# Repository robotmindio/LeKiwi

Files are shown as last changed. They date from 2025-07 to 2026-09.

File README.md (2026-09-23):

# LeKiwi
<div style="display: flex; justify-content: center; align-items: center; padding: 25px;">
    
    
    
    
</div>

> LeKiwi - Low-Cost Mobile Manipulator | Version 1

  

## Step by step tutorial
1. [Bill of Materials](BOM.md)
2. [3D Printing](3DPrinting.md)
3. [Assembly](Assembly.md)
4. [Get started with LeRobot](https://huggingface.co/docs/lerobot/lekiwi)

## Hardware Design
#### Standardized Stacked Base Plates
- Inspired by the [open robotic platform](https://openroboticplatform.com/designrules), our base plates have 3.5mm diameter holes spaced 20mm apart for standardized mounting

#### Power
- (12V version) 12v 5A Li-ion battery
- (5V version) 65W Laptop power bank

> [!TIP]  
> If this is the first time you build robots please choose the 5V version as it’s a little bit easier to assemble. If you are more experienced and want to lift heavier objects choose the 12V version. If you want the cheapest option possible go for the wired LeKiwi version.

#### Compute
- Raspberry Pi 5
- Streaming to a Laptop

#### Drive
- 3-wheel Kiwi (holonomic) drive with omni wheels

#### Robot Arm
- [SO-ARM101](https://github.com/TheRobotStudio/SO-ARM100) ([pinned local CAD source](cad/upstream/SO-ARM100/))

#### Sensors
- Workspace rgb camera
- Wrist rgb camera

## Software Capabilities
Goals:
- Teleoperation with controller or laptop WASD + leader arm
- Data collection pipeline
- Streaming joint angles and camera feed

## CAD Design
[Fusion 360 CAD](https://a360.co/4k1P8yO)

We also provide the [URDF](./URDF/) exported from CAD for simulation.

The open CAD migration is in [cad/](cad/): `LeKiwi_reference.FCStd` preserves the complete STEP reference assembly, while `LeKiwi.FCStd` supplies the editable chassis and accessories. The full Xacro combines that export with the pinned official SO-101 follower model; it keeps LeRobot's stable joint names and the SO-101 kinematics and travel limits. The arm and RobotSkin LD06 sources are pinned in [cad/upstream/](cad/upstream/); initialize them with `git submodule update --init --recursive`. See the [deterministic rebuild instructions](cad/README.md).

The [manufacturing source index](manufacturing/) is the authoritative answer to
what can be edited, cut, or only printed as an STL. It covers every released
print, both laser-cut plates, and the currently identified sourced hardware.

## Check out our Dynamixel Version!
<div style="display: flex; justify-content: center; align-items: center; padding: 25px;">
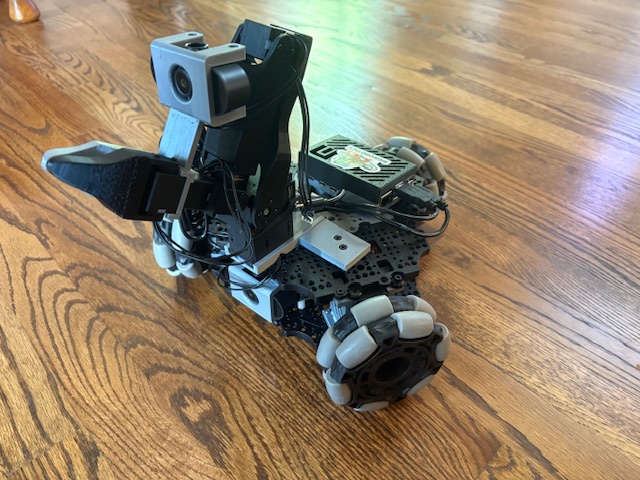
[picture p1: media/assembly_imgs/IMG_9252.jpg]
     
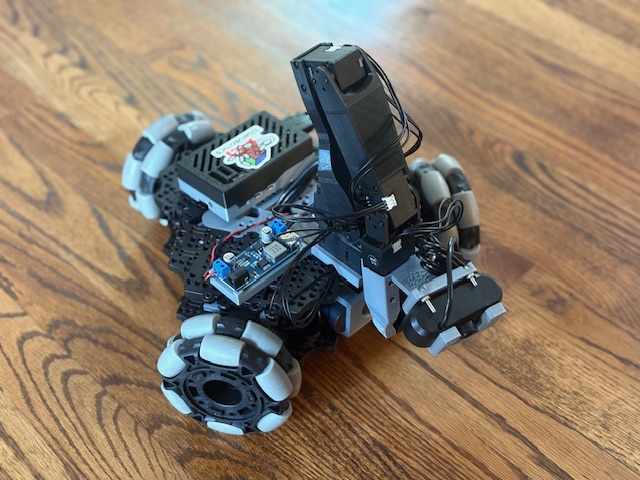
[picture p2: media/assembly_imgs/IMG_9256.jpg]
     
</div>

We converted LeKiwi to use ROBOTIS components by using the Koch v1.1 arm, U2D2 motor controller, and Dynamixel XL430 motors for the mobile base.  [Dynamixel LeKiwi](DynamixelLeKiwi)

## Get In Touch!

Join the project on LeRobot's [Discord server](https://discord.gg/Jtz5TJtb2u) (channel `mobile-so100-arm`)! Let us know if you have any questions, suggestions, or other feedback.

## Citation

If you use LeKiwi in your research, please cite the repository using the metadata in [CITATION.cff](CITATION.cff). GitHub's **Cite this repository** menu provides APA and BibTeX citations.

## Main Contributors
Thank you to everyone who helped on the project!

**CAD Design**: Manav Chandaka, Bhargav Chandaka, Pepijn Kooijmans

**Software**: Pepijn Kooijmans, Gloria Wang, Bhargav Chandaka, Advait Patel

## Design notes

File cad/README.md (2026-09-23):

# Open CAD migration

`assembly/LeKiwi_reference.FCStd` is the complete Fusion STEP export imported into FreeCAD. It is the dimensional reference; STEP cannot retain Fusion sketches or its feature timeline.

`assembly/LeKiwi.FCStd` is the open CAD-to-ROS source for the chassis and accessories. Its active `CadParts` retain the 47-link reference assembly:

- 2 editable FreeCAD laser-cut extrusions;
- 10 links driven by 6 native parametric FreeCAD printed-part sources;
- 23 STEP BREP references; and
- 10 canonical URDF mesh references where the STEP and URDF exports differ by more than 2%; and
- the RobotSkin LD06 base plus lidar body and compact Astra Pro mount.

The final 36-link Xacro replaces that reference assembly's legacy arm subtree with the pinned SO-101 model described below and omits the removed Pi case. The exact source and validation result for every retained CAD link is recorded in [reference_mapping.json](reference_mapping.json). The RobotSkin LD06 body is authored directly in `LeKiwi.FCStd`; its mount and the compact Astra mount are regenerated from their OpenSCAD sources before every export. The hidden `LeKiwiReferenceParts` group is retained only for placement and validation; it is not the geometry exported for a reauthored part.

## Development prerequisites

- **FreeCAD** (tested against the version pinned by the [Flathub `org.freecad.FreeCAD`](https://flathub.org/apps/org.freecad.FreeCAD) package): `scripts/run_freecad_script.sh` launches it as `flatpak run --command=FreeCADCmd org.freecad.FreeCAD`. See `scripts/install_freecad.sh`.
- **OpenSCAD**, on `PATH`, for the RobotSkin lidar/Astra mounts, RobotSkin surfaces, and the reverse-engineered print sources.
- **xacro** and **check_urdf** (ROS Jazzy: `source /opt/ros/jazzy/setup.bash`) to expand and validate the generated Xacro, as `verify_xacro.py` does.
- **Python packages** in [requirements.txt](../requirements.txt) (`pip install -r requirements.txt`) for the scripts that run under plain `python3` rather than FreeCAD's interpreter: trimesh, numpy, shapely, pytest, and vtk for the RobotSkin renderers.
- **CadQuery**: `export_robot.sh` requires it for the native SO-101 wrist. `cad/cadquery/requirements.txt` pins the version CI installs into its own environment; if CadQuery is not installed in the default `python3`, set `CADQUERY_PYTHON` to the interpreter of an environment that has it, e.g. `CADQUERY_PYTHON=/path/to/venv/bin/python3 ./scripts/export_robot.sh`.

## Arm source

The upstream [SO-ARM100](upstream/SO-ARM100/) repository is a pinned Git submodule at
commit `7629d2ad9853d10fb903093a33ef6114099d97e5` under its Apache-2.0 license. The
final URDF and Xacro use its official `Simulation/SO101/so101_new_calib.urdf`
follower model and meshes. `scripts/replace_arm_with_so101.py` performs the one
deterministic integration step: it prefixes the arm links to avoid the ROS
`base_link`, preserves the official inertias, axes, origins, and limits, and maps
the six joints onto LeRobot's stable `arm_*` names.

`cadquery/so101_wrist.py` loads the official STEP geometry for the follower wrist
motor holder and roll carrier. Part 8, the wrist-flex body, is rebuilt from native
CadQuery sketches and features in `cadquery/so101_part8.py`; the STEP remains only
the dimensional reference. Run `python cad/cadquery/test_so101_wrist.py` with
CadQuery installed to check the native solid and the unchanged reference parts.

The export uses that native part 8 as `meshes/so101/native_wrist_flex.stl`, in
the official wrist mesh frame and converted from millimetres to metres.
All other arm meshes are refreshed from the pinned upstream source on every
export. `export_robot.sh` requires CadQuery; set `CADQUERY_PYTHON` to the Python
executable of an existing CadQuery environment if it is not installed in the
default interpreter. `verify_robot.sh` runs its STEP-fidelity check first.
`cad/cadquery/requirements.txt` pins the CadQuery version CI uses.
The export also writes `URDF/LeKiwi.urdf`, the plain-URDF expansion of the Xacro
for consumers without xacro; `URDF/LeKiwi.baseline.urdf` is the original
upstream model that the migration and semantics checks compare against.
`verify_robot.sh` rebuilds everything in a scratch directory and fails if the
committed Xacro, URDF or meshes differ from that rebuild; CI runs it on every
push. The complete export also records `URDF/model-manifest.json`. Run
`python3 scripts/model_manifest.py --check` to detect source or output changes
since the last export; the ROS vendor script runs this check before copying.

The SO-101 base placement is derived from the original assembly's shoulder-pan
datum, not copied from the legacy base-part origin. The importer composes the
CAD joint chain and preserves the shoulder centre and bending plane, then
turns the installed SO-101 outward toward CAD +Y (ROS +X), the arm/fixed-camera
side confirmed by the operator. This half-turn is not a calibration offset.
The pan-frame orientations themselves differ between SO-100 and SO-101;
copying their orientations turns the arm's bending plane by a quarter turn.
Moving that datum in the assembly therefore moves the exported arm correctly.
Both sensor brackets attach to the upper plate's top surface at local z=7 mm.
The lidar reuses the removed Pi case's screw pair at x=+/-20, y=-100 mm,
plus the corresponding y=-80 mm row. Its bracket faces rearward; the lidar
centre is x=-5, y=-135 mm. `verify_sensor_mounts.py` checks all four fasteners
against the actual upper-plate contours. The historical Pi case mounting
datum is retained in `URDF/LeKiwi.baseline.urdf`, not as installed case geometry.
The Astra uses the diagonal pair nearest the operator's two fingernails:
CAD (-100, -20) and (-80, -60) mm, separated by sqrt(2000) = 44.721 mm.
Its bracket centre is (-90, -40, 7) mm and its local yaw is 116.565 degrees,
26.565 degrees counterclockwise from the previous left-facing placement.
The camera faces outward left/rear, retaining the 8-degree downward pitch.

Initialize it after cloning, then check the expected source bundle:

```sh
git submodule update --init --recursive
./scripts/verify_arm_sources.sh
```

The LeKiwi-specific `modified_base_arm` and legacy webcam gripper insert remain
separate prints; they are not part of the SO-101 robot description.

## Link identifiers

Names such as `ST3215_Servo_Motor-v1-1` and
`4-Omni-Directional-Wheel_Single_Body-v1-2` are unique Fusion-assembly
occurrence identifiers, not a sequence of part revisions. Each needs its own
URDF link and pose even when the physical component is the same. Do not delete
or merge them merely because their filenames share a `-1` or `-2` suffix.

## RobotSkin source

`upstream/RobotSkin/` is pinned at commit `b028a962e99f8a84eaebfe314e63373a82edc8c1`.
Its `scad/parts/lekiwi-lidar-base.scad` entry point and shared
`scad/lib/robotskin.scad` implementation generate the lidar mount. The generated
mesh lives under ignored `cad/generated/`; `export_robot.sh` rebuilds it and updates
the assembly before writing the URDF meshes and Xacro.

## Native printed-part sources

The complete LeKiwi-specific manufactured set represented by the URDF is editable in [parts/](parts/README.md): the two laser-cut plates plus `drive_motor_mount.FCStd`, `omni_wheel_mount.FCStd`, `servo_controller_mount.FCStd`, `lipo_battery_mount.FCStd`, `base_camera_mount.FCStd`, and `wrist_camera_mount.FCStd`.

Each printed-part file has an `Editable dimensions` (`Parameters`) object and a normal FreeCAD feature tree ending in `Final`; it contains profile features, Part extrusions, primitives, fuses, and cuts—not an imported mesh or opaque BREP wrapper. Open a source file in FreeCAD, change a parameter or profile feature, and save it. Then relink and regenerate:

```sh
make link-native-part-sources
./scripts/export_robot.sh
make verify-native-part-sources
```

`build_native_part_sources.sh` reconstructs the six initial source files from the validated STEP/STL references. It intentionally overwrites those source files, so use it to reset or regenerate a baseline, not after manual edits you intend to keep.

Four models preserve their STEP component frame. The omni-wheel source uses the canonical URDF mesh frame; the drive-motor source uses the user-selected `3DPrintMeshes/drive_motor_mount_v2.stl` frame. Both use editable native features derived from STL sections. The linker's validation must remain below the 2% geometry tolerance before it saves the assembly.

The v2 motor cages measure 47.5 × 34.8 × 45.5 mm installed. Their three placements
are aligned to the existing chassis bolt holes, 1.25 mm inset from the flats.
`scripts/install_wheel_mount_v2.py --apply` updates the six cage/servo joint poses,
the visible complete wheel units and `wheel_mount_v2_poses.json`; without `--apply`
it checks the installation. Six rods occupy (±100, 0) and (±60, ±80) mm.
RobotSkin uses 4 mm per-side wheel-unit clearance from this corrected geometry.

Published, non-URDF accessory sources live in [accessories/](accessories/README.md). At present, the two webcam mounts have exact LeKiwi STEP sources and are imported as editable BREP documents; their source files are not duplicated or hand-recreated.

## Deterministic build

After changing a source or robot metadata, run:

```sh
./scripts/verify_robot.sh
```

The verifier generates the assembly, meshes, and Xacro under a temporary build
directory and removes it when finished, so checking the model does not rewrite
the source tree. Run `export_robot.sh` when the validated generated files should
be promoted into `URDF/`. It exports the FreeCAD link sources to
`URDF/meshes/reauthored/`, replaces the legacy arm subtree with the pinned
SO-101 follower, and writes the complete Xacro. There is no hand-edited Xacro
step. `verify_cad_migration.sh` checks every retained CAD link against the
baseline URDF; the SO-101 links remain verified directly against their pinned
upstream source.

The slower reconstruction of legacy and recovery manufacturing files is a
separate audit because those files do not feed the robot Xacro:

```sh
./scripts/verify_manufacturing.sh
```

`native_parts.json` is the source of truth for the six parametric printed-part documents, their assembly links, and their placement references.

For a stricter shape-fidelity audit, run:

```sh
make compare-reauthored-assets
```

It compares each native FreeCAD export with its configured reference mesh using
bidirectional sampled surface distance and fails on more than 0.25 mm maximum
or 0.10 mm 95th-percentile deviation. Pass `ARGS=--report-only` to only write
the comparison report without failing the run. The checked-in baseline
uses the v2 STL for all three motor cages (0.211 mm maximum, 0.041 mm p95
sampled deviation); this remains separate from the older bounding-box and volume check.
`verify_robot.sh` runs this check in its strict (default) mode.

## Mass and inertia

Native source links deliberately keep `UseCadMass=False` until a real material density or printed mass is known. After choosing material or measuring a finished part, activate CAD-derived mass, centre of mass, and the full inertia tensor for the relevant assembly link:

```sh
make attach-cad-part ARGS="cad/assembly/LeKiwi.FCStd drive_motor_mount-v11-2 CadDriveMotorMountV11_2 1240 0"
./scripts/export_robot.sh
```

Here `1240` is only an example density in kg/m³. Use a measured printed mass instead of `0` for FDM or assembled parts; it accounts for infill, walls, and hardware. The exporter combines all solid CAD parts in a link with the parallel-axis theorem. Purchased components should use measured or vendor mass overrides. `verify_xacro.py` does not exact-match a `UseCadMass=True` link's `<inertial>` against the baseline URDF (which never had real CAD mass); instead it checks the exported mass and inertia tensor physically: positive finite mass, a positive-definite inertia tensor, and principal moments that satisfy the rotational triangle inequality.

Chassis joint metadata remains editable in the `LeKiwiJoints` group. SO-101 joint names, parents, children, axes, origins, and limits come from the pinned upstream URDF; together they form the deterministic composite Xacro contract.

### Measured chassis rod placements

The six screws identified by the operator in the marked underside photograph
are existing 20 mm-grid holes at `(±100, 0)` and `(±60, ±80)` mm. The working
`assembly/LeKiwi.FCStd` places all six existing rods there, with no central rod.
The visible rod placements and their ROS joint poses are both corrected. The
upper plate remains at `(0, 0, 50)` mm; its joint offset compensates for moving
the rod that is its parent. The original `LeKiwi_reference.FCStd` stays unchanged.

Run `./scripts/run_freecad_script.sh scripts/correct_chassis_rods.py` to verify
all six placements against holes in both editable plates. Add `--apply` to
reapply this measured layout. This does not resize the motor stands. Regenerate
RobotSkin exports after chassis corrections; old generated skins are not current.

## Rebuild after replacing the Fusion STEP export

```sh
make import-step-reference
make seed-robot-metadata
make build-laser-plate-sources
make verify-laser-plate-sources
make build-native-part-sources
./scripts/migrate_reference_links.sh --apply
make link-base-plate-sources
make link-native-part-sources
./scripts/migrate_reference_links.sh --apply
./scripts/run_freecad_script.sh scripts/correct_chassis_rods.py --apply
./scripts/run_freecad_script.sh scripts/install_wheel_mount_v2.py --apply
./scripts/export_robot.sh
make verify-native-part-sources
```

`correct_chassis_rods.py --apply` and `install_wheel_mount_v2.py --apply` must
run after the assembly's base plates and native parts are linked (so their
holes and reference geometry exist to validate against) and before the final
`export_robot.sh`, so the corrected chassis-rod and v2 wheel-mount placements
are baked into `cad/assembly/LeKiwi.FCStd` before the Xacro and meshes are
generated from it.

The first migration pass creates hidden placement references. The second records the validated native sources after they have been linked.

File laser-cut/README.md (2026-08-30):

# Laser-cut base plates

`generated/` contains the editable, millimetre DXF profiles for the lower and
upper base plates used by the validated Fusion/URDF assembly. They are the
canonical cut geometry; [`base_plates.scad`](base_plates.scad) selects one for
convenient OpenSCAD export, and `build_laser_plate_sources.py` turns each into
its FreeCAD extrusion source.

`generated/print-templates/` contains matching 1:1 PDF templates for paper printing. Print at **Actual size / 100%** (never “Fit to page”); each PDF page is 216 × 213 mm. If the printer crops them, use the `*_tiled_a4.pdf` version: print both A4 pages at 100%, cut on the dashed `CORTAR/UNIR` line, and tape the two halves together.

Export a selected profile to another DXF with OpenSCAD:

```sh
openscad -D 'plate="lower"' -o /tmp/base_plate_lower.dxf base_plates.scad
openscad -D 'plate="upper"' -o /tmp/base_plate_upper.dxf base_plates.scad
```

They match the current assembly plates, including through-holes and upper-plate
cutouts. The older `3DPrintMeshes/base_plate_layer2.stl` has a different
outline; its separate editable legacy profile is tracked with the standard
reverse-engineered print sources. Set material thickness and kerf compensation
in the laser-cutter software; neither changes the 2D profile.

The native Fusion archive, whole-assembly STEP, and whole-assembly DXF are retained in `../reference/fusion/`. The Fusion archive is the only export that preserves the original feature history.

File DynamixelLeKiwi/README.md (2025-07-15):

# Our Dynamixel Version!

 

 

1. Buy the parts following the [BOM](BOM.md)
2. Print all the parts listed in [3DPrinting](3DPrinting.md)
3. Follow our [Assembly](Assembly.md) to build the dynamixel LeKiwi

## Modified Lerobot Code For Teleoperation 

Here are the changes we made to the original LeKiwi code: [Dynamixel Teleop](https://github.com/SIGRobotics-UIUC/lerobot/commit/cc4adff50d33ef14ab579abfe554689732d0e5e5)

You can follow the original LeKiwi documentation with this modified code. Make sure to change ports, ips, etc. for your specific setup.

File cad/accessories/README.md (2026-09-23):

# Published accessory sources

The [RobotSkin chassis overlays](ROBOTSKIN_SURFACES.md) cover the exterior top,
interior floor and interior ceiling. Their OpenSCAD recipe derives clearances
from the installed chassis and builds a separate FreeCAD review assembly.

This directory contains FreeCAD documents only when an exact, redistributable
editable source is already published with LeKiwi. They are intentionally kept
outside the URDF assembly: webcam mounts are alternative camera hardware, not
the Arducam configuration represented in `LeKiwi.FCStd`.

| Accessory | Published source | FreeCAD document | Source kind |
| --- | --- | --- | --- |
| Webcam base mount | `3DPrintMeshes/webcam_mount/webcam_mount.step` | `webcam_base_mount.FCStd` | Imported STEP BREP |
| Webcam wrist mount | `3DPrintMeshes/webcam_mount/webcam_mount_wrist.step` | `webcam_wrist_mount.FCStd` | Imported STEP BREP |
| SO-100 webcam gripper insert | `cad/upstream/SO-ARM100/STEP/SO100/Follower_Specific/Wrist_Roll_08c v1.step` + editable M3 clearance and hex-nut pocket | `so100_gripper_cam_mount_insert.FCStd` | SO-ARM100 STEP derivative |

## Compact base-removed Astra Pro mount

[`astra_pro_compact_mount.scad`](astra_pro_compact_mount.scad) is a direct,
low-profile adapter for the clear space between two wheels. It keeps the camera
upright at 8 degrees downward pitch. The base has two blind M3 insert sockets at
44 mm centres;
the camera saddle has two M2 holes at 18.0 mm centres and a
26.2 x 7.4 x 6.3 mm pocket. Its plan dimensions use the measured 0.6 and
1.3 mm play in the previous 26.6 x 8.5 mm print, leaving 0.2 mm total clearance
on each axis. The M2 holes remain centered in the pocket on the lens-to-USB
axis. Their head-access bores are 4.7 mm for the measured 4.5 mm screw heads.

The camera contact plane is only 15.5 mm above the LeKiwi plate. Heat-set two
M3x4x4 inserts from below into the large plate-facing surface, attach the camera
using its M2x8 screws, then drive the M3 screws upward through the LeKiwi plate.
The 4.0 mm diameter sockets are 4.2 mm deep; tune `m3_insert_hole` if the actual
insert or printer needs a different fit. Print flat on its base:

```sh
openscad --export-format binstl -o 3DPrintMeshes/astra_pro_compact_mount.stl cad/accessories/astra_pro_compact_mount.scad
```

Build or reset those documents, then verify that they still match their
corresponding print STLs:

```sh
make build-accessory-sources
make verify-accessory-sources
```

These are editable Open STEP BREP documents in FreeCAD's Part workbench. The
SO-100 derivative keeps its upstream wrist-roll BREP and its M3 camera-mount
boss as a separate editable cylinder/fuse. The upstream wrist-roll revision is
within 0.191% by volume but differs by 2.325% in bounding box from LeKiwi's
legacy print, so this derivative is not presented as an exact reconstruction.
None are claimed to reconstruct the original parametric feature history.

## External or non-identical sources

| Accessory family | Source found | Why it remains external |
| --- | --- | --- |
| Raspberry Pi case top and bottom | [Printables model 605060](https://www.printables.com/model/605060-raspberry-pi-5-case-wpower-button-v2) publishes STEP files | Its CC BY-NC terms cannot be silently relicensed under this repository's Apache-2.0 license. The LeKiwi STLs are described as modified from that model, so the public STEP is not assumed to be an exact replacement either. |
| Standard SO-100/SO-101 arm | [TheRobotStudio/SO-ARM100](../upstream/SO-ARM100/) publishes Apache-2.0 STEP sources | The repository is pinned as a Git submodule. The SO-100 follower source is checked by `scripts/verify_arm_sources.sh`; `modified_base_arm` is not verified as an exact upstream part. |
| VEX-derived wheel hub | VEX provides downloadable CAD for its parts | `servo_wheel_hub.stl` is documented as modified from a VersaHub, not as an unmodified vendor part. No exact Apache-compatible source for the LeKiwi derivative was established, so the vendor file is not vendored here. |

## Reauthoring candidates with no exact editable source located

The search covered the LeKiwi repository history, its Fusion archive, and the
published upstream projects above. The following print assets still need a
native reauthoring if they are to become editable FreeCAD sources:

- `3DPrintMeshes/battery_mount_eu.stl` and `5v_specific/5v_power_bank_holder.stl`
- `3DPrintMeshes/drive_motor_mount_v2.stl`
- `3DPrintMeshes/modified_base_arm.stl`, `jetson_holder.stl`, and `wrist_camera_mount.stl`
- `3DPrintMeshes/wired_specific/cable_holder v0.stl` and `wired_specific/usb_connector_case v1.stl`
- `3DPrintMeshes/dynamixel_specific/Dynamixel_omni_wheel_mount v2.stl`, `center_triangular_insert.stl`, `dynamixel_drive_motor_mount.stl`, `dynamixel_kiwi_servo_mount.stl`, `dynamixel_modified_base_arm.stl`, `dynamixel_wheel_hub .stl`, `follower_base.stl`, `modified_static_side_with_mount.stl`, `pi_case_bottom.stl`, and `webcam_base_mount.stl`

`drive_motor_mount.stl`, `servo_wheel_hub.stl`, `servo_controller_mount.stl`,
`battery_mount.stl`, `base_camera_mount.stl`, and
`dynamixel_specific/lipo_battery_mount.stl` correspond to existing native
URDF sources, so they are not missing-source candidates.

The `drive_motor_mount_v2.stl` and `wrist_camera_mount.stl` print revisions do
not match their older URDF counterparts, so the current native URDF sources
must not be presented as editable sources for those two files.

The core URDF source files in `cad/parts/` are tracked separately. Their
current geometric-fidelity audit is recorded in
`cad/validation/reauthored_asset_comparison.json`; all twelve native link
instances pass its sampled surface criterion. That validation does not extend
to the alternative accessory prints listed above.

## Core native-source fidelity

The two laser plates and all six native printed sources pass the strict
bidirectional sampled surface audit against their corresponding original URDF
meshes. The maximum measured deviation is 0.056 mm and the largest 95th
percentile is 0.034 mm.

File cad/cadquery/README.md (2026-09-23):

# Part 8 physical simplification

`so101_part8_simplified.py` replaces a curved section of the lower skirts with
a planar facet between the motor rails and the lower seat. The cut starts
beyond the rails at x=-10.5 mm and stops before the seat at x=9.8 mm. Keeping
the rail support intact limits how much of this contour can be straightened.

This version modifies the exact pinned upstream STEP. It is **STEP-backed**,
not a new native reconstruction. `so101_part8.py` remains the separate native
approximation used by the robot exporter; this candidate does not replace it.

The original source is loaded once with `so101_wrist.load_part("flex_body")`
and passed to `part8_simplified(original)`. Both the source geometry and the
comparison therefore use one source of truth. The recipe contains only the
facet coordinates and extrusion; mounting geometry is not duplicated.
`cad_checks.py` shares solid comparison and STL validation/export, and
`render_stl_comparison.py` can compare other arm meshes at matching scales.

## Reproduce

From the repository root, using an interpreter with CadQuery and its VTK
dependency installed:

```sh
python cad/cadquery/test_so101_part8_simplified.py
python cad/cadquery/render_stl_comparison.py \
  cad/generated/part8/so101_part8_original.stl \
  cad/generated/part8/so101_part8_simplified.stl \
  cad/generated/part8/comparison.png
```

The check exports both STL files in millimetres and the same coordinate frame,
plus `comparison.json` with source hash, geometric measurements and mesh checks.

## What is checked

- Both solids and both boolean differences must be valid. Equal-volume boxes
  at different positions serve as a negative control for shape equality.
- No added material, so the candidate cannot introduce a new geometric
  collision at any joint angle. This preserves existing clearance; it does
  not certify that the original assembly itself is collision-free.
- The original cylindrical mounting faces retain their topology. Protected
  regions around the motor rails/heel, roof/ears, seat/foot and clip lose no
  material. No joint frame, axis or mounting location is moved.
- Both STL meshes must be closed, manifold and connected, and their volumes
  must agree with CAD within 0.1%. Export uses absolute 0.02 mm deflection.
  VTK removes zero-area facets caused by binary STL rounding; holes are not
  patched and surfaces are not smoothed. CAD volume accounting permits 1 mm³
  integration error on split spline faces, separately from the zero-addition
  shape check.

This is a conservative geometric prototype. Material, layer orientation,
supports, stiffness and fatigue have not been physically qualified. Closed
STL geometry does not establish support-free printing or equal strength.
Further structural simplification needs the intended loads and print setup.

## Single-piece rounded redesign

`so101_part8_serviceable.py` retains its historical filename but now builds
**one piece**: a smooth motor cradle with integral curved sides and a mirrored
fork. The cover builders, seams, windows, screw bosses, inserts, cable-tie
tunnels and cover calibration parameters are gone. The outside is 37 mm wide,
versus 34 mm for the preceding single-piece version, and its nose extends
4 mm farther forward. This extra envelope lets the housing wrap around the
lower seat instead of leaving an external shelf. The motor opening stays open;
this is not a sealed enclosure or a lightweight optimization.

The fork no longer has separate flared collars. Its inner junctions are blended
after union with the housing; the rear outer face meets the back curve without
a bottom-edge fillet interrupting the join. R60 side surfaces and R3 edge blends
replace the shallower R80 sides and R2 rim. A tangent-ended lower profile flows
down to the seat, and the deck's exposed upper edges have R0.6 rounding. Sharp
motor-contact and access edges are not indiscriminately rounded.

The bottom tooth is removed at the user's request. It previously contacted the
rotating wrist outside the configured motion range, consistent with a travel
stop. **That mechanical stop no longer exists.** The software limits have not
been expanded; do not assume the old physical end-stop/calibration behavior.

The incoming wrist-flex axis stays at (-18.1, 0, 28) mm along X and outgoing
wrist-roll at (0, 0, -33.1) mm along Z, within the pinned URDF's rounding.
Motor placement, joint transforms, link lengths and software limits are unchanged.
Mass, stiffness and payload capacity are not guaranteed equivalent.

This remains a hybrid native/STEP-backed design. Native rounded geometry defines
the shell and fork; exact source patches retain the motor contacts, rails,
joint faces and mounting holes. The lower-seat patch ends at Z=-34.4 mm rather
than importing the tooth underneath, and is limited to Y=±12.4 mm so it does not
restore the old outer skirt edges. This retains the motor seats and the mounting
counterbores (which reach Y=±12.25 mm). The deck retains the original planar
contact footprint and access opening. The original source is never modified.

### Generate and inspect

```sh
python cad/cadquery/test_so101_part8_serviceable.py
python cad/cadquery/render_part8_serviceable.py
```

Current outputs are in **`cad/generated/part8-smooth/`**:

- `original.stl` and `cradle.stl`: matching original assembly coordinates, mm.
- `cradle_print.stl`: the same single part oriented with its left ear down.
  Inspect supports for the deck and lower seat in your slicer; this is not a
  support-free or physically qualified print.
- `cradle.step`: editable solid.
- `preview.png`: actual original/redesign/underside views at equal scale.
- `details.png`: close-up fork/deck, front opening, rear and underside views.
- `checks.json`: source hashes, exact-interface and sampled-clearance results.

The older `part8-serviceable/` generated files are superseded. They are not
outputs of this builder; do not print their covers for this version.

### Assembly and checks

Use the original motor/joint hardware. There are no additional cover screws or
heat-set inserts. The open front provides motor access; the fork-root opening
clears the motor's top tab. Removing the motor still requires its fasteners and
possibly the neighboring joint to be removed.

Checks compare added/removed material in the five protected contact regions and
counterbore seating layers—not just total volume. They also check the empty
counterbores, absence of the tooth and old raised deck fragments, uninterrupted
side walls, and absence of the old fork-patch seam. Each STL must be closed,
manifold, connected and within 0.1% of CAD volume.

The actual pinned motor and immediate neighboring meshes are sampled across
259 configurations, with wrist angle spacing no greater than 2°. New
penetration beyond 0.08 mm relative to upstream fails. Front motor entry is
also compared to upstream in both sampling directions at 61 translations over
60 mm. The source model already has clip/guide interference, so this is **not**
proof of a rigid, force-free insertion path.

These are finite geometric checks, not continuous swept-volume proof, whole-arm
collision certification, or bench validation. Physical assembly, cable routing,
print fit, cooling, strength and fatigue still need testing. Start with a fit
prototype and retain the software motion limits.

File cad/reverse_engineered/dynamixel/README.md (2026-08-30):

# Dynamixel print sources

`parts.json` is the source and validation manifest for every Dynamixel-specific
print.  It records the original STL's unit conversion, the canonical editable
source, and the bidirectional surface-comparison result.  Native Fusion files
remain at [the public Fusion share](https://a360.co/44YAcMn): it has no stated
redistribution licence, so this repository stores stable component identifiers
and hashes instead of a copy.

## Local sources

The three legacy prints not currently validated as matching exportable Fusion
bodies are editable locally.  `dynamixel.scad` reconstructs the arm and drive
mount from closed DXF sections; `lipo_battery_mount.scad` is a direct parametric
tray model.  All dimensions are millimetres.  Build ignored STLs locally with:

```sh
cd cad/reverse_engineered/dynamixel
openscad -D 'part="dynamixel_modified_base_arm"' -o generated/dynamixel_modified_base_arm.stl dynamixel.scad
openscad -D 'part="dynamixel_drive_motor_mount"' -o generated/dynamixel_drive_motor_mount.stl dynamixel.scad
openscad -o generated/lipo_battery_mount.stl lipo_battery_mount.scad
```

The arm uses the coarsest tested 16-section stack that passes the 0.25 mm maximum
and 0.10 mm p95 surface gate.  The drive mount uses the coarsest tested passing
uniform stack: 230 sections at 0.239565210757 mm.

## Static-side patch

Open the `Static Side Gripper` source from the public Fusion share, select its
small BRep body, and run `patch_static_legacy_hole.py` from Fusion's Scripts and
Add-Ins dialog.  It adds the one missing legacy R3.149941806669 mm finite
through-hole as a native Combine/Cut feature.  Export the patched body together
with the unchanged large Static Side Gripper body to produce the original
two-body print.

`validation/verify_static_composition.py` is a manual external-source
composition check.  Export both public-source bodies as separate, uncommitted
STLs: the unpatched small body first and the unchanged large body second.  Run
the verifier in FreeCAD's Python console.  It directly performs a
bidirectional *sampled* surface comparison for the large body against its own
target component.  For the small body, it checks sampled source-to-target and
target-to-source distances outside exactly the 52 fitted hole faces, then checks
the fitted faces against the patch radius and finite endpoints.  It reports
`compositional_pass`, deliberately distinct from a direct patched-small-body
export comparison; the public STEP proxy is not used as an export surrogate.

```python
import runpy, sys
sys.argv = [
    "verify_static_composition.py",
    "/absolute/path/to/static_a_small_body.stl",
    "/absolute/path/to/static_b_large_body.stl",
]
_ = runpy.run_path("/absolute/path/to/verify_static_composition.py", run_name="__main__")
```

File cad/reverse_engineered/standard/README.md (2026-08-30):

# Standard LeKiwi print-source recovery

`standard.scad` has one selector per reauthored solid.  For example:

```sh
openscad -D 'part="servo_wheel_hub"' -o generated/servo_wheel_hub.stl standard.scad
```

`legacy_base_plate_layer2.dxf` is an editable 2D cut contour; its SCAD file
extrudes it to the original 7 mm thickness.  The three Fusion entries retain
their original feature-history members in `LeKiwi.f3z`; their exported solids
are surface-validated in `validation/provenance.json`.

The mesh-only solids use editable DXF section stacks.  `parts.json` maps each
part to its selector and `validation/results.json` records its surface check.
The strict gate is the shared `compare_reauthored_assets.py --mesh-align`
check: 1,024 deterministic bidirectional surface samples.
Jetson's original STL has overlapping bodies, so its three watertight bodies
are checked separately and the `jetson_holder` selector is only their preview
union.

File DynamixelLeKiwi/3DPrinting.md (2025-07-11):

# 3D Printing
> **Estimated time:** ~34 hours

We provide ready-to-print STL files for the 3D-printed parts below. These can be printed with generic PLA filament on consumer-grade FDM printers. We tested on a [Bambu Lab P1S](https://us.store.bambulab.com/products/p1s) printer. For all components, we just load into bambuslicer, auto-rotate and auto-arrange, enable any recommended supports, and print.

## Parts

| Item | Quantity | Notes | 
|:---|:---:|:---:|
| [Center triangular insert](/3DPrintMeshes/dynamixel_specific/center_triangular_insert.stl) | 2 |  |
| [Dynamixel Drive motor mount](/3DPrintMeshes/dynamixel_specific/dynamixel_kiwi_servo_mount.stl) | 3 | |
| [Dynamixel Servo wheel hub](/3DPrintMeshes/dynamixel_specific/Dynamixel_omni_wheel_mount%20v2.stl) | 3 | Use Supports<sup>[1](#footnote1)</sup> | |
| [Lipo battery mount](/3DPrintMeshes/dynamixel_specific/lipo_battery_mount.stl) | 1 | |
| [RasPi case Top](/3DPrintMeshes/pi_case_top.stl) | 1 | <sup>[2](#footnote2)</sup> |
| [RasPi case Bottom](/3DPrintMeshes/dynamixel_specific/pi_case_bottom.stl) | 1 | <sup>[2](#footnote2)</sup> ||
| Webcam [base mount](/3DPrintMeshes/dynamixel_specific/webcam_base_mount.stl), [static gripper w/ mount](/3DPrintMeshes/dynamixel_specific/modified_static_side_with_mount.stl) | 1 | **Compatible with [this camera](https://www.amazon.fr/Vinmooog-equipement-Microphone-Enregistrement-conférences/dp/B0BG1YJWFN/)** |
| [Modified Follower Arm Base](/3DPrintMeshes/dynamixel_specific/follower_base.stl) | 1 |  |
| [Follower arm](https://github.com/jess-moss/koch-v1-1) | 1 |Use with the modified base and static gripper  |
| [Leader arm](https://github.com/jess-moss/koch-v1-1) | 1 | |

> **Note**: Make sure to enable supports where specified!

## Printing Instructions
Assuming you already have access to a 3D printer<sup>[3](#footnote3)</sup>, follow these steps to print all the parts above.

### 1. Setup Printer
1. Calibrate the printer and level beds according to printer-specific instructions
2. Clean the print bed
3. Load-in filament

### 2. Print the Parts
1. Upload STL file to printing/slicing software. Auto-rotate and auto-arrange. 
2. Enable supports if specified and slice. We tested with the following settings:
    - Infill Density: 15%
    - Layer Height: 0.2 mm
    - Printing Speed: 150 mm/s
3. If needed, upload G-code (slice file) to printer and print

### 3. Take Down
1. Remove printed part(s) from printer
2. Clean print bed if needed
3. Remove any supports from printed parts

> For tutorials on how to assemble the robot, checkout the [Assembly](Assembly.md) page!

## Footnotes
<a name="footnote1">1</a>: Modified from [VEX VersaHub model](https://www.vexrobotics.com/versahubs.html?srsltid=AfmBOooDKLcAfkuEgHyrjk24WFDrLTP4TQWkGjEpC-9HcyaMMCUMDSzs)

<a name="footnote2">2</a>: Modified from [Micro Center model](https://www.printables.com/model/605060-raspberry-pi-5-case-wpower-button-v2)

<a name="footnote3">3</a>: If not, we recommend [Bambu Lab](https://bambulab.com/en-us) or [Prusa](https://www.prusa3d.com/), or checkout this [list of brands](https://github.com/ad-si/awesome-3d-printing?tab=readme-ov-file#3d-printer-brands).

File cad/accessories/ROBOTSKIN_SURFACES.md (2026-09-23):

# Superficies RobotSkin para LeKiwi

Tres recubrimientos de 4 mm: `top.stl` (Z=57–61), `floor.stl` (Z=0–4) y
`ceiling.stl` (Z=46–50, puertos hacia abajo), en milímetros del chasis.

## Fuente de las posiciones

El soporte autoritativo es `3DPrintMeshes/drive_motor_mount_v2.stl`, indicado
por el usuario. Su reconstrucción paramétrica mide **47.5 × 34.8 × 45.5 mm**
(ancho tangencial × profundidad radial × altura instalada), no 50 × 37 mm.
Los cuatro ejes de fijación de cada soporte coinciden con agujeros del chasis;
el borde exterior queda 1.25 mm dentro del segmento plano. Las tres unidades
se orientan a 120°, con los ejes de rueda radiales y los planos tangenciales.

Soportes, motores, cubos, ruedas y seis separadores se obtienen de los `CadParts`
activos y las posiciones articulares de `cad/assembly/LeKiwi.FCStd`.
Los separadores están en (±100, 0) y (±60, ±80) mm, en los tornillos señalados.
El brazo SO-101 y los accesorios conservan sus transformaciones actuales.

Los recortes reservan **4 mm por cada lado** de las envolventes convexas XY
de las unidades de rueda que alcanzan la altura de cada piel. La huella nominal
del soporte con ese margen mide 55.5 × 42.8 mm; otros componentes pueden
ampliar el recorte. `--motor-clearance` ajusta el margen independientemente
de las otras holguras. `motor_bases` conserva las huellas y recortes verificados.
El techo también deja espacio para los soportes de 45.5 mm de altura.
Los seis separadores se comprueban en las tres pieles.
Las dos ventanas de cables se derivan del perfil CAD superior: 60 × 20 mm
centrada en (0, 0) y 20 × 30 mm en (0, 50), ambas con esquinas R4.
Son aproximaciones de la fotografía usando la retícula de 20 mm, no medidas
con calibre. El techo conserva ambas; la piel superior también las despeja,
aunque pueden unirse al recorte del brazo. El piso no cambia.
La holgura general se ajusta con `--clearance` (0.5–3 mm); el borde exterior queda
0.5 mm dentro del perímetro de la placa. Los componentes electrónicos no
recortan la piel: se remontarán encima, según el montaje solicitado.

## Fijación usando los puertos normales

No hay agujeros adicionales para fijar la piel. Todos los puertos usan `port_cut()`
y el paso central de `through_plate()` de la biblioteca RobotSkin existente.
La retícula de 10 mm parte del origen del chasis, por lo que coincide con su
retícula de tornillos de 20 mm. `chassis_ports` en `checks.json` enumera los
puertos que coinciden con agujeros físicos utilizables de cada placa.

Las cuatro fijaciones del brazo señaladas en la foto tienen claros independientes
de Ø12 mm para cabezas, tuercas y arandelas, derivados de los agujeros mayores
del CAD superior: (-31.727, 25.225), (31.773, 25.225), (-27.753, 95) y
(27.799, 95) mm. `--arm-fastener-diameter` permite ajustar el acceso (8–16 mm)
a la tornillería real. El techo contiene los cuatro agujeros; en la piel superior
quedan dentro del recorte abierto del brazo. No se taladra ni se cambia la placa.
Esta corrección no modifica la colocación del brazo en el ensamblaje.
El STEP `Base_SO101.step` confirma el patrón: pares de 63.5 y 55.55 mm de ancho,
separados 69.775 mm. Los claros siguen los agujeros físicos confirmados, no el
desplazamiento de la instancia del brazo; ese desfase CAD permanece sin corregir.

Fijar las pieles por esos mismos puertos, con tornillos M3 y los insertos de
RobotSkin. Usar un único inserto por unión: no enroscar un tornillo a través
de dos insertos enfrentados. La placa superior con sus dos pieles suma 15 mm;
la inferior con su piel suma 11 mm. Elegir la longitud según cabeza, arandelas
y enganche del inserto. Se conservan los ajustes de impresión `RM_PORT_FIT`,
`RM_PEG_FIT` y `RM_INSERT_BORE` de la biblioteca fijada por LeKiwi.

## Regenerar e inspeccionar

Requiere FreeCAD Flatpak, OpenSCAD y Python con trimesh, Shapely 2 y rtree;
las imágenes usan VTK. Desde la raíz del repositorio:

```sh
./scripts/build_robotskin_surfaces.sh
python3 scripts/render_robotskin_surfaces.py
python3 scripts/render_robotskin_assembly.py
```

Resultados en `cad/generated/robotskin/`:

- `top.stl`, `floor.stl`, `ceiling.stl`: impresión con puertos arriba y base Z=0.
  El techo se refleja en Y para recuperar las coordenadas CAD al voltearlo.
- `LeKiwi_RobotSkin.FCStd`: ensamblaje de revisión con las pieles instaladas.
- `preview.png`: las tres pieles y despiece.
- `full_build.png`, `wheel_assemblies.png`: CAD corregido y unidades de rueda.
- `floor_base_fit.png`: STL del piso y huellas v2 con 4 mm por lado.
- `floor_wheel_fit.png`: piso instalado y conjuntos completos de rueda.
- `upper_windows.png`: ventanas del CAD superior y techo en coordenadas instaladas.
- `arm_fastener_access.png`: cuatro accesos del brazo resaltados en verde.
- `checks.json`, `wheel_orientation_checks.json`: geometría, fijaciones y ejes.

Las verificaciones exigen mallas cerradas y conectadas, grosor de 4 mm, paso
central libre en todos los puertos y caras dentro de las envolventes comprobadas
(tolerancia STL de 0.002 mm). Los componentes que se remontarán se muestran en sus
posiciones de referencia en la vista del robot completo.

La altura interior libre queda en 42 mm. Las piezas caben aproximadamente en
215 × 212 mm. Falta la prueba física de ajuste, incluida la tornillería real
del brazo, y no se certifica el barrido completo de sus seis ejes.

La referencia de servo tiene pequeñas intersecciones de esquina con el soporte
v2 (menos de 1 mm³ por unidad, también presentes contra el STL original).
Esto no es una colisión con RobotSkin ni una certificación de ajuste físico
servo/soporte. No se ha deformado el soporte oficial para ocultarlas.

Verificación del 2026-09-08: `verify_robot.sh`, `compare_reauthored_assets.sh --strict`,
`verify_robotskin_surfaces.py`, `correct_chassis_rods.py` e `install_wheel_mount_v2.py`
aprobados; la revisión con ventanas también pasa `verify_laser_plate_sources.sh`,
el ensayo completo del robot, la comparación estricta y la comprobación de las
tres pieles. Puertos con ventanas y accesos del brazo: superior 172, piso 222,
techo 178. Piso y techo
conservan seis agujeros independientes para separadores; dos claros superiores
se abren al recorte del brazo. Desviación máxima eje/radio en las tres ruedas:
0.172°. Las imágenes proceden de geometría CAD/STL, no de una ilustración generada.

2026-09-09: los cuatro accesos confirmados del brazo pasan la verificación de
posiciones, diámetros y exclusión de todas las caras STL en ambas pieles superiores.
Las tres mallas siguen cerradas, conectadas y con 4 mm de grosor; placa y brazo
no se han modificado. La revisión instalada se actualiza en `LeKiwi_RobotSkin.FCStd`.

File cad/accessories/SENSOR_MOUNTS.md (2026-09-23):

# Sensor mounts

Generated from `sensor_mount_spec.json`; edit that file and run
`scripts/sync_sensor_mount_spec.py`.

- LD06 mount origin (m): `[0.0, -0.115, 0.007]`
- LD06 body centre in mount (m): `[0.02, -0.005, 0.012]`
- Astra plate holes (mm): `[[-80.0, -60.0, 7.0], [-100.0, -20.0, 7.0]]`
- Astra mount origin (m): `[-0.09, -0.04, 0.007]`
- Astra pitch: `8.0 deg`
- RPi 5 12x10 through-plate origin (m): `[0.125, -0.075, 0.007]`, yaw `-1.5707963267948966` rad
- RPi 5 through-plate bolt stations (plate mm): `[[-55.0, -25.0], [-35.0, -45.0]]`
- RPi 5 carrier and table sit on the plate at (m): `[0.0, 0.0, 0.004]`

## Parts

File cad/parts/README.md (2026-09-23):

# Native LeKiwi part sources

All LeKiwi-specific manufactured parts represented by the URDF assembly now have editable FreeCAD sources. `LeKiwi.FCStd` links each source's `Final` feature into the appropriate URDF link, so mesh and Xacro regeneration is deterministic.

| Manufactured component | Source file | URDF links | Status |
| --- | --- | --- | --- |
| Lower base plate | `base_plate_lower.FCStd` | `base_plate_layer1-v5` | Laser-profile extrusion |
| Upper base plate | `base_plate_upper.FCStd` | `base_plate_layer2-v3` | Laser-profile extrusion |
| Drive motor mount | `drive_motor_mount.FCStd` | `drive_motor_mount-v11*` | Native parametric source |
| Omni-wheel mount | `omni_wheel_mount.FCStd` | `omni_wheel_mount-v5*` | Native parametric source |
| Servo controller mount | `servo_controller_mount.FCStd` | `servo_controller_mount-v3` | Native parametric source |
| LiPo battery mount | `lipo_battery_mount.FCStd` | `lipo_battery_mount-v3` | Native parametric source |
| Base camera mount | `base_camera_mount.FCStd` | `Camera-Mount-v8` | Native parametric source |
| Wrist camera mount | `wrist_camera_mount.FCStd` | `Wrist-Camera-Mount-v11` | Native parametric source |

Open a source file in FreeCAD and edit its `Parameters` object or its named profile/Part features. Save it, then run:

```sh
make link-native-part-sources
./scripts/export_robot.sh
make verify-native-part-sources
```

The first command replaces only the managed native `CadParts` links and verifies their bounding boxes and volumes against the baseline. It leaves `UseCadMass=False`; set an actual printed mass or density with `attach_cad_part.py` (via `make attach-cad-part ARGS="..."`) before asking the Xacro exporter to calculate inertia.

To recreate the initial six models from the reference STEP and canonical STL files, run:

```sh
make build-native-part-sources
make link-native-part-sources
./scripts/export_robot.sh
make verify-native-part-sources
```

The builder overwrites these six `.FCStd` files. It is a reset tool, not a save operation for manual changes.

The source models use independent FreeCAD profile features and standard Part operations; none embeds an external mesh or BREP as its final solid. The wrist-camera mount keeps one hidden `InterfaceClearance` BREP cut tool derived from the Fusion XRef it must fit; its surrounding body, plate, bosses, and holes remain native FreeCAD features. Their dimensional starting points came from the Fusion STEP export, except the omni-wheel mount, whose canonical URDF STL revision is the authoritative geometry. The Fusion archive embeds proprietary `.f3d` files, but its timeline has no reliable open-source importer.

`verify_native_part_sources.py` checks the native feature-tree contract and the
2% bounds/volume placement tolerance. It is not a surface-equivalence test.
Run `make compare-reauthored-assets` for the stricter bidirectional
mesh audit. The checked-in report passes all eleven active native link instances
against the configured STEP/STL references, including the user-selected v2 cage.
The v2 rebuild's sampled deviation is 0.211 mm maximum and 0.041 mm p95;
the audit limits are 0.25 mm maximum and 0.10 mm p95.

The drive-motor source now follows `3DPrintMeshes/drive_motor_mount_v2.stl`
(SHA256 `9ad701cf2c012c735edac7867db5e3b8f24142a89b58cb0f7729b1d9a2c9615b`).
Installed dimensions are 47.5 × 34.8 × 45.5 mm; native structural extrusions,
mounting holes, counterbores and editable vent profiles replace the old tray.
Only the small vent chamfers use 0.1 mm stepped sections.
Rebuild just this source with `run_freecad_script.sh scripts/build_drive_motor_mount_v2.py`,
then link it and run `run_freecad_script.sh scripts/install_wheel_mount_v2.py --apply`.
The installer checks all twelve chassis bolt axes and preserves complete wheel units.
RobotSkin adds 4 mm per-side clearance; it does not enlarge the mount itself.

Purchased or separately maintained designs, and optional accessory prints outside this URDF assembly, remain measured/vendor references rather than reverse-engineered LeKiwi-specific source models.

The upper plate includes two photo-approximated rounded cable windows (R4):
60 × 20 mm at (0, 0) and 20 × 30 mm at (0, 50), in chassis millimetres.
`scripts/upper_plate_windows.py` replaces the original single opening while
preserving the perimeter and remaining screw holes. The plate builder applies
this correction after importing the historical DXF; that DXF remains unchanged.
RobotSkin reads the resulting CAD contours for both upper overlays.

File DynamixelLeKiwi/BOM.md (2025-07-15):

# Bill of Materials

This page provides a complete list of parts needed to build the Dynamixel LeKiwi mobile manipulator. Our total cost is displayed in the table <sup>[1](#footnote1)</sup>.

| Price| US  | EU  | CN |
|---|----:|----:|----:|
| **Dynamixel LeKiwi** |  **$770.47**  |  **€1021.60**  |  **¥6074**  ||
| **Base only** |  **$339.47**  |  **€378.60**  |  **¥2127.28**  |

> [!NOTE] 
> Prices and items may vary depending on geographic location and time of purchase. If you find links for other countries or cheaper suppliers, please create an issue or PR so that we add them to the list!

### Mobile Base Structure:
| Part | Amount | Unit Cost (US) | Buy (US) | Unit Cost (EU) | Buy (EU) | Unit Cost (CN) | Buy (CN) |
| - | - | - | - | - | - | - | - |
| 4" Omni wheels | 3 | $9.99 | [VEX Robotics](https://www.vexrobotics.com/omni-wheels.html?srsltid=AfmBOorWdWT-FIiWSAbicYWSxqYr-d5X3CJSGxMkO33WO0thwlTn4DQu) | €24.5 | [RobotShop](https://eu.robotshop.com/products/100mm-omnidirectional-wheel-brass-bearing-rollers) |￥135 |[PDD](https://mobile.yangkeduo.com/goods.html?ps=kKWPC7xuzw "https://mobile.yangkeduo.com/goods.html?ps=kKWPC7xuzw")|
| M2 M3 M4 Assorted Screw Set | 1 | $14.99 | [Amazon](https://www.amazon.com/Button-Socket-Washers-Assortment-Machine/dp/B0BMQGJP3F) | €23.5 | [Amazon](https://www.amazon.fr/Cylindrique-Inoxydable-M2-Socket-Assortiment/dp/B09Y8WYFWD/) |￥25 |[Taobao（M2x5+M3套装+M3x10+M4x12）](https://e.tb.cn/h.64O1J2A9Is4pIJd "https://e.tb.cn/h.64O1J2A9Is4pIJd") 
| TB3 Waffle Plate Set | 1 | $19.00 | [ROBOTIS](https://en.robotis.com/shop_en/item.php?it_id=903-0259-000) | €16.3 | [ROBOTIS](https://en.robotis.com/shop_en/item.php?it_id=903-0259-000) |￥136 |[Robotis US (ships to China)](https://en.robotis.com/shop_en/item.php?it_id=903-0259-000) |
| **Total** || **$63.96** || **€€113.30** || **¥566** ||

### Sensors and Compute:

| Part| Amount | Unit Cost (US) | Buy (US) | Unit Cost (EU) | Buy (EU) |  Unit Cost (CN) | Buy (CN) |
|--|:-:|:-:|-|:-:|-|:-:|-|
| Raspberry Pi 5 (4GB)| 1 |$60.00| [Adafruit](https://www.adafruit.com/product/5812)| €57.00| [Mouser](https://eu.mouser.com/ProductDetail/Raspberry-Pi/SC1111?qs=HoCaDK9Nz5fnLhlMNnKTiQ%3D%3D)|￥410|[Taobao](https://e.tb.cn/h.64IIvlisvAL15g8?tk=fdOVexkHECW "https://e.tb.cn/h.64IIvlisvAL15g8?tk=fdOVexkHECW")|
| USB camera<sup>[2](#footnote2)</sup> | 2 | $12.98 | [Amazon](https://a.co/d/236G8Wn) | €12.00 | [Amazon](https://www.amazon.fr/Vinmooog-equipement-Microphone-Enregistrement-conf%C3%A9rences/dp/B0BG1YJWFN/) |￥48|[Taobao](https://e.tb.cn/h.64ILq3suMKATfUx?tk=IPSEexQAvxu "https://e.tb.cn/h.64ILq3suMKATfUx?tk=IPSEexQAvxu")|
| microSD card | 1 | $11.23 | [Amazon](https://www.amazon.com/SanDisk-Extreme-microSDXC-Memory-Adapter/dp/B09X7C7LL1/) | €10.00 | [Amazon](https://www.amazon.fr/Lexar-Carte-Micro-adaptateur-Smartphone/dp/B08XZ2KS1F)|￥58|[Taobao](https://e.tb.cn/h.64DMZzLz5h26s12?tk=eImPex96lCQ "https://e.tb.cn/h.64DMZzLz5h26s12?tk=eImPex96lCQ")|
| U2D2_INT | 1 | $32.10 | [ROBOTIS](https://en.robotis.com/shop_en/item.php?it_id=902-0132-000) | €27.93 | [ROBOTIS](https://en.robotis.com/shop_en/item.php?it_id=902-0132-000)|￥230.73|[ROBOTIS](https://en.robotis.com/shop_en/item.php?it_id=902-0132-000)|
| U2D2 PHB | 1 | $19.00 | [ROBOTIS](https://en.robotis.com/shop_en/item.php?it_id=902-0145-001) | €16.53 | [ROBOTIS](https://en.robotis.com/shop_en/item.php?it_id=902-0145-001)|￥136.57|[ROBOTIS](https://en.robotis.com/shop_en/item.php?it_id=902-0145-001)|
| **Total** ||  **$135.31**  ||  **€123.46** ||  **¥883.3** ||

### Other
| Part| Amount | Unit Cost (US) | Buy (US) | Unit Cost (EU) | Buy (EU) | Unit Cost (CN) | Buy (CN) |
|--|:-:|:-:|-|:-:|-|:-:|-|
| Table Clamp 4pcs | 1 | $18 | [Amazon](https://www.amazon.com/WORKPRO-Clamps-Woodworking-One-Handed-Spreader/dp/B0CQYDJWS8/) | € 21 | [Amazon](https://www.amazon.fr/dp/B08HW9VFM8/)| ¥10.8\*4  |[Taobao](https://e.tb.cn/h.64r5eomI6L59tBE?tk=gZWeex9fnlB "https://e.tb.cn/h.64r5eomI6L59tBE?tk=gZWeex9fnlB")|
| Screwdriver Set | 1 | $6 | [Amazon](https://www.amazon.com/Precision-Phillips-Screwdriver-Electronics-Computer/dp/B0DB227RTH) | €10 | [Amazon](https://www.amazon.fr/dp/B08ZXVMVYD/) | ￥20 |[Taobao](https://e.tb.cn/h.6ReL0wwgtPuSmNV?tk=3rLDV10AVtr)  |
| USB-C to USB-A Cable 2 pcs | 1 | $7 | [Amazon](https://www.amazon.com/Charging-etguuds-Charger-Braided-Compatible/dp/B0B8NWLLW2/?th=1) | €7 | [Amazon](https://www.amazon.fr/dp/B07BNF842T/) |￥17  |[Taobao](https://e.tb.cn/h.64HOv24RLmYC4Yh?tk=AXpgexkDFd4 "https://e.tb.cn/h.64HOv24RLmYC4Yh?tk=AXpgexkDFd4")|
| **Total** ||  **$31**  ||  **€38** || **¥80.20** ||

### Mobile Base Electronics
| Part | Amount | Unit Cost (US) | Buy (US) | Unit Cost (EU) | Buy (EU) | Unit Cost (CN) | Buy (CN) |
|:---|:---:|:---:|:---|:---:|---:|:-:|-|
| 12v 5a Battery | 1 | $32.99 | [Amazon](https://www.amazon.com/KBT-Rechargeable-Connector-Replacement-Security/dp/B0C242DYT1/ref=sr_1_2_sspa?) | €45.79 | [Amazon](https://www.amazon.fr/dp/B0D5QSMW21) | ￥70 |[Taobao](https://e.tb.cn/h.64IJNTnXwhn44BS?tk=PQQ8exkJEtR "https://e.tb.cn/h.64IJNTnXwhn44BS?tk=PQQ8exkJEtR")|
| Lever Wire Connector | 1 | $6.70 | [Amazon](https://www.amazon.com/Wago-221-413-LEVER-NUTS-Conductor-Connectors/dp/B06XGYXVXR/ref=sr_1_4) | €7.18 | [Amazon](https://www.amazon.fr/221-413-fil-électrique-connecteur-220-240-Terminal/dp/B01AKF3I58) | ￥3.50 |[Taobao](https://e.tb.cn/h.64r0Z6Y5jZczq5q?tk=XEaSex908q0 "https://e.tb.cn/h.64r0Z6Y5jZczq5q?tk=XEaSex908q0")|
| 12v 5a DC plug connector | 1 | $9.49 | [Amazon](https://www.amazon.com/43x2pcs-Connectors-Security-Lighting-MILAPEAK/dp/B072BXB2Y8/ref=sr_1_11) | €8.99 | [Amazon](https://www.amazon.fr/RUNCCI-YUN-Alimentation-dalimentation-Connecteur-Surveiller/dp/B0CX44HTKZ) | ￥3.10 |[Taobao](https://e.tb.cn/h.64IFOvrMdUVoQQX?tk=nahtexkvokE "https://e.tb.cn/h.64IFOvrMdUVoQQX?tk=nahtexkvokE")|
| 12v to 5v 5a USB-C converter | 1 | $9.99 | [Amazon](https://www.amazon.com/Klnuoxj-Converter-Interface-Waterproof-Compatible/dp/B0CRVW7N2J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) | €9.99 | [Amazon](https://www.amazon.fr/Greluma-convertisseur-Adaptateur-dalimentation-Compatible/dp/B0D7VDL2X6) | ￥20 |[1688](https://qr.1688.com/s/Eb6ykv4y "https://qr.1688.com/s/Eb6ykv4y") |
| DYNAMIXEL XL430-W250-T | 3 | $27.00 | [ROBOTIS](https://www.robotis.us/dynamixel-xl430-w250-t/) | €23.16 | [ROBOTIS](https://www.robotis.us/dynamixel-xl430-w250-t/)  | ￥193.76 |[ROBOTIS](https://www.robotis.us/dynamixel-xl430-w250-t/)|
| **Total** | | **$140.17** | | **€141.80** | | **￥677.88** | |

### Koch v1.1 2 Robot Arm Teleoperation Set 
Use  https://github.com/jess-moss/koch-v1-1 

#### Leader Arm
| Part | Amount | Unit Cost (US) | Buy US | Unit Cost (EU) | Buy EU | Unit Cost (UK) | Buy UK | Unit Cost (RMB) | Buy CN | Unit Cost (JPY) | Buy JP |
|---|---|---|---|---|---|---|---|---|---|---|---|
| Dynamixel XL330-M077-T | 6 | $24 | [Robotis](https://www.robotis.us/dynamixel-xl330-m077-t) | 40€ | [MyBotShop](https://www.mybotshop.de/DYNAMIXEL-XL330-M077-T)-[GenRobots](https://www.generationrobots.com/en/403818-dynamixel-xl330-m077-t-servo-motor.html) | £27 | [RoboSavvy](https://robosavvy.co.uk/robotis-dynamixel-xl330-m077-t.html) | ¥255 | [TaoBao](https://item.taobao.com/item.htm?id=651202518645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.) | ¥4,070 | [Robotis](https://e-shop.robotis.co.jp/product.php?id=416) |
| XL330 Frame and Idler Wheel 4pcs set<sup>[1](#myfootnote1)</sup> |  1 | $10 | [Robotis](https://www.robotis.us/fpx330-h101-4pcs-set) | 12€ | [MyBotShop](https://www.mybotshop.de/DYNAMIXEL-FPX330-H101-4PCS-Set)-[GenRobots](https://www.generationrobots.com/en/403860-FPX330-H101-hinge-frame-and-idler-set-dynamixel-xl330.html) | £10 |  [RoboSavvy](https://robosavvy.co.uk/fpx330-h101-4pcs-set.html) | ¥100 | [TaoBao](https://item.taobao.com/item.htm?id=646782958666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..) | ¥2,024 | [Robotis](https://e-shop.robotis.co.jp/product.php?id=437) |
| Waveshare Serial Bus Servo Driver Board | 1 | $10 | [Amazon](https://a.co/d/7C3RUYU) | 6€ | [Eckstein](https://eckstein-shop.de/WaveShare-Serial-Bus-Servo-Driver-Board-for-ST-SC-Serial-Bus-Servos-EN) | £11 | [Amazon](https://www.amazon.co.uk/Waveshare-Integrates-Control-Applicable-Integrate/dp/B0CJ6TP3TP/)| ¥24 | [TaoBao](https://item.taobao.com/item.htm?id=739743280684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) | n/a | n/a |
| 5V Power Supply | 1 | $6 | [Amazon](https://a.co/d/5u90NVp) | 9€ | [Amazon](https://www.amazon.fr/LEYF-Alimentation-Universelle-Adaptateur-Enfichable/dp/B09NGVWBSY) | £10 | [Amazon](https://www.amazon.co.uk/Adapter-Switching-100-240V-5-5x2-1mm-Transformer-5V2A-UKCA/dp/B0CH6HFVTK/)| ¥10 | [TaoBao](https://detail.tmall.com/item.htm?id=662655385028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) | ¥899 | [Amazon](https://a.co/d/5u90NVp) |
| Jumper Wires 3*40 pcs set (M-M, M-F, F-F) | 1 | $7 | [Amazon](https://a.co/d/hQfk2cb) | 9€ | [Amazon](https://www.amazon.fr/dp/B0BRMKX5RT/) | £5 | [Amazon](https://www.amazon.co.uk/dp/B09KGRM98K/)| ¥10 | [TaoBao](https://detail.tmall.com/item.htm?id=608543275703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) | n/a | n/a |
| Table Clamp | 1 | $6 | [Amazon](https://a.co/d/4KEiYdV) | n/a | n/a | £14 | [Amazon](https://www.amazon.co.uk/BESSEY-TOOLS-CM30-Forged-C-Clamp/dp/B0006694I2/?th=1)| ¥8 | [TaoBao](https://detail.tmall.com/item.htm?id=597606333219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..) | n/a | n/a |
| Table Clamp 4pcs set<sup>[2](#myfootnote2)</sup> | 1 | n/a | n/a | 14€ | [Amazon](https://www.amazon.fr/CAUTIOUS-Serre-Joint-R%C3%A9glable-Serre-Joints/dp/B0CJMB3SKH) | n/a | n/a | n/a | n/a | n/a | n/a |
| 1.5mm Star/Cruciform Screwdriver 2pcs set | 1 |  $7 | [Amazon](https://www.amazon.com/HARFINGTON-Precision-Screwdriver-Eyeglasses-Electronic/dp/B0D3XQ97XM/?th=1)| 7€ | [Amazon](https://www.amazon.fr/sourcing-map-Cruciforme-%C3%89lectroniques-R%C3%A9paration/dp/B0BQ69J2QF) | £4 | [Amazon](https://www.amazon.co.uk/sourcing-map-Screwdriver-Eyeglasses-Electronics/dp/B0BLM2Y2Z5/) | ¥2 | [TaoBao](https://detail.tmall.com/item.htm?id=790258857614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) | n/a | n/a |
| USB C-A or C-C 2pcs set<sup>[3](#myfootnote3)</sup> | 1 | $9 | [Amazon](https://www.amazon.com/Charging-etguuds-Charger-Braided-Compatible/dp/B0B8NWLLW2/) | 8€ | [Amazon](https://www.amazon.fr/dp/B08J7PQGD7/) | £6 | [Amazon](https://www.amazon.co.uk/Anker-Charger-Braided-Standard-Charging/dp/B07DD5YHMH/)| ¥12 | [TaoBao](https://detail.tmall.com/item.htm?id=44425281296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) | n/a | n/a |
| Total | | $199 | | 305€ | | £222 | | ¥1696 | | ¥6993 | |

#### Follower Arm

| Part | Amount | Unit Cost (US) | Buy US | Unit Cost (EU) | Buy EU | Unit Cost (UK) | Buy UK | Unit Cost (RMB) | Buy CN | Unit Cost (JPY) | Buy JP
|---|---|---|---|---|---|---|---|---|---|---|---|
| Dynamixel XL430-W250-T |  2 | $27 | [Robotis](https://www.robotis.us/dynamixel-xl430-w250-t) | 44€ | [MyBotShop](https://www.mybotshop.de/DYNAMIXEL-XL430-W250-T)-[GenRobots](https://www.generationrobots.com/en/402823-dynamixel-xl430-w250-t-servomotor.html) | £47 | [RoboSavvy](https://robosavvy.co.uk/dynamixel-xl430-w250-t.html) | ¥485 | [TaoBao](https://item.taobao.com/item.htm?id=588178867677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) | ¥6,831 | [Robotis](https://e-shop.robotis.co.jp/product.php?id=40)
| Dynamixel XL330-M288-T |  4 | $24  | [Robotis](https://www.robotis.us/dynamixel-xl330-m288-t) | 40-46€ | [MyBotShop](https://www.mybotshop.de/DYNAMIXEL-XL330-M288-T)-[GenRobots](https://www.generationrobots.com/en/403817-dynamixel-xl330-m288-t-servo-motor.html) | £27 | [RoboSavvy](https://robosavvy.co.uk/robotis-dynamixel-xl330-m288-t.html) | ¥255 | [TaoBao](https://item.taobao.com/item.htm?id=648175925849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) | ¥4,070 | [Robotis](https://e-shop.robotis.co.jp/product.php?id=417)
| XL330 Frame and Idler Wheel 4pcs set<sup>[1](#myfootnote1)</sup> |  1 | $10 | [Robotis](https://www.robotis.us/fpx330-h101-4pcs-set) | 12€ | [MyBotShop](https://www.mybotshop.de/DYNAMIXEL-FPX330-H101-4PCS-Set)-[GenRobots](https://www.generationrobots.com/en/403860-FPX330-H101-hinge-frame-and-idler-set-dynamixel-xl330.html) | £10 |  [RoboSavvy](https://robosavvy.co.uk/fpx330-h101-4pcs-set.html) | ¥100 | [TaoBao](https://item.taobao.com/item.htm?id=646782958666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..) | ¥2,024 | [Robotis](https://e-shop.robotis.co.jp/product.php?id=437) |
| XL430 Idler Wheel set | 1 | $7 | [Robotis](https://www.robotis.us/hn11-i101-set) | 9€ | [MyBotShop](https://www.mybotshop.de/DYNAMIXEL-XL430-HN11-I101-Set)-[GenRobots](https://www.generationrobots.com/en/403206-hn11-i101-horn-set.html) | £7 | [Robosavvy](https://robosavvy.co.uk/hn11-i101-set.html)| ¥75 | [TaoBao](https://item.taobao.com/item.htm?id=581922883001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..) | ¥836 | [Robotis](https://e-shop.robotis.co.jp/product.php?id=147)
| Waveshare Serial Bus Servo Driver Board | 1 | $10 | [Amazon](https://a.co/d/7C3RUYU) | 6€ | [Eckstein](https://eckstein-shop.de/WaveShare-Serial-Bus-Servo-Driver-Board-for-ST-SC-Serial-Bus-Servos-EN) | £11 | [Amazon](https://www.amazon.co.uk/Waveshare-Integrates-Control-Applicable-Integrate/dp/B0CJ6TP3TP/)| ¥24 | [TaoBao](https://item.taobao.com/item.htm?id=739743280684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) | n/a | n/a |
| Voltage Reducer | 1 | $14 | [Amazon](https://www.amazon.com/EPLZON-Converter-5V-5-3V-Transformer-Regulator/dp/B09R4DBZJK) | 14€ | [Amazon](https://www.amazon.fr/dp/B0B58T2YY8/) | £15 | [Amazon](https://www.amazon.co.uk/Converter-Voltage-Regulator-Transformer-Charging/dp/B0989DKYWN) | ¥11 | [TaoBao](https://detail.tmall.com/item.htm?id=617425895508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) | n/a | n/a |
| 12V Power Supply | 1 | $12 | [Amazon](https://a.co/d/40o8uMN) | 15-36€ | [Amazon](https://www.amazon.fr/LEDMO-Alimentation-Adaptateur-Transformateurs-Chargeur/dp/B07PGLXK4X)-[GenRobots](https://www.generationrobots.com/en/400866-smps-charger-for-bioloid-and-dynamixel-robotis.html) | £13 | [Amazon](https://www.amazon.co.uk/Facmogu-Adapter-100-240V-Monitors-Amplifier/dp/B0CXPMJJMF/) | ¥20 | [TaoBao](https://detail.tmall.com/item.htm?id=678305663026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) | ¥1,685 | [Amazon](https://a.co/d/40o8uMN) |
| Jumper Wires 3*40 pcs set (M-M, M-F, F-F) | 1 | $7 | [Amazon](https://a.co/d/hQfk2cb) | 9€ | [Amazon](https://www.amazon.fr/dp/B0BRMKX5RT/) | £5 | [Amazon](https://www.amazon.co.uk/dp/B09KGRM98K/)| ¥10 | [TaoBao](https://detail.tmall.com/item.htm?id=608543275703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) | n/a | n/a |
| Table Clamp | 1 | $6 | [Amazon](https://a.co/d/4KEiYdV) | n/a | n/a | £14 | [Amazon](https://www.amazon.co.uk/BESSEY-TOOLS-CM30-Forged-C-Clamp/dp/B0006694I2/?th=1) | ¥8 | [TaoBao](https://detail.tmall.com/item.htm?id=597606333219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..) | n/a | n/a |
| Table Clamp 4pcs set<sup>[4](#myfootnote4)</sup> | 1 | n/a | n/a | 14€ | [Amazon](https://www.amazon.fr/CAUTIOUS-Serre-Joint-R%C3%A9glable-Serre-Joints/dp/B0CJMB3SKH) | n/a | n/a | n/a | n/a | n/a | n/a |
| 1.5mm Star/Cruciform Screwdriver 2pcs set<sup>[4](#myfootnote5)</sup> | 1 |  $7 | [Amazon](https://www.amazon.com/HARFINGTON-Precision-Screwdriver-Eyeglasses-Electronic/dp/B0D3XQ97XM/?th=1)| 7€ | [Amazon](https://www.amazon.fr/sourcing-map-Cruciforme-%C3%89lectroniques-R%C3%A9paration/dp/B0BQ69J2QF) | £4 | [Amazon](https://www.amazon.co.uk/sourcing-map-Screwdriver-Eyeglasses-Electronics/dp/B0BLM2Y2Z5/) | ¥2 | [TaoBao](https://detail.tmall.com/item.htm?id=790258857614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) | n/a | n/a |
| USB C-A or C-C 2pcs set<sup>[6](#myfootnote6)</sup> | 1 | $9 | [Amazon](https://www.amazon.com/Charging-etguuds-Charger-Braided-Compatible/dp/B0B8NWLLW2/) | 8€ | [Amazon](https://www.amazon.fr/dp/B08J7PQGD7/) | £6 | [Amazon](https://www.amazon.co.uk/Anker-Charger-Braided-Standard-Charging/dp/B07DD5YHMH/)| ¥12 | [TaoBao](https://detail.tmall.com/item.htm?id=44425281296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) | n/a | n/a |
| Total | | $232 | | 338€ | | £285 | | ¥2251 | | ¥15446 | |

> Head to [3D Printing](3DPrinting.md) for the next step!

<br></br>

## Footnotes
<a name="footnote1">1</a>: Doesn't include cost of 3D printing

<a name="footnote2">2</a>: Another supported camera option is the Arducam 5MP Wide Angle found [here](https://www.amazon.com/Arducam-Camera-Computer-Without-Microphone/dp/B0972KK7BC)

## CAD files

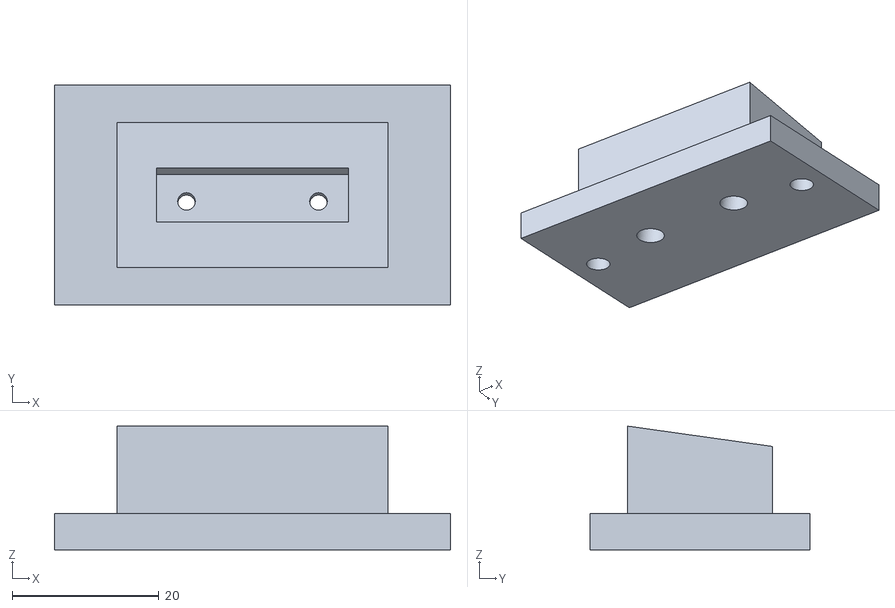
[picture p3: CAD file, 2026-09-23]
3DPrintMeshes/astra_pro_compact_mount.stl
54.0 x 30.0 x 16.9

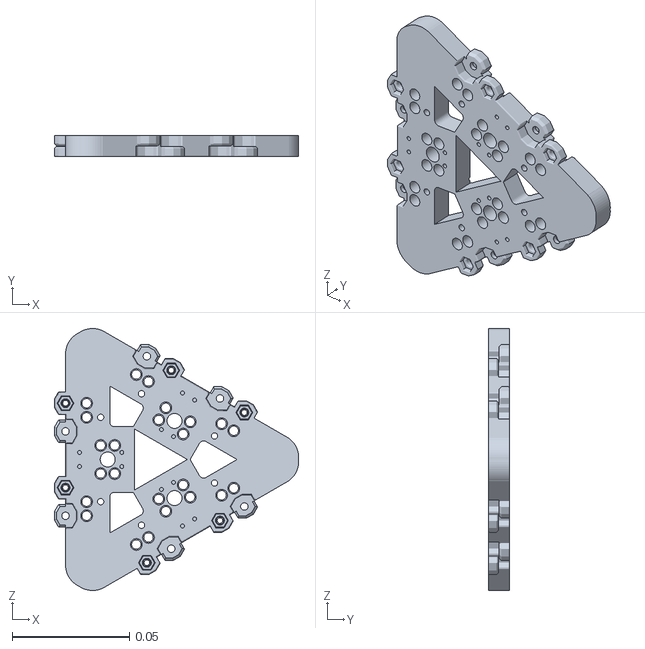
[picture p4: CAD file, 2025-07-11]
3DPrintMeshes/dynamixel_specific/center_triangular_insert.stl
0.104 x 0.009 x 0.112

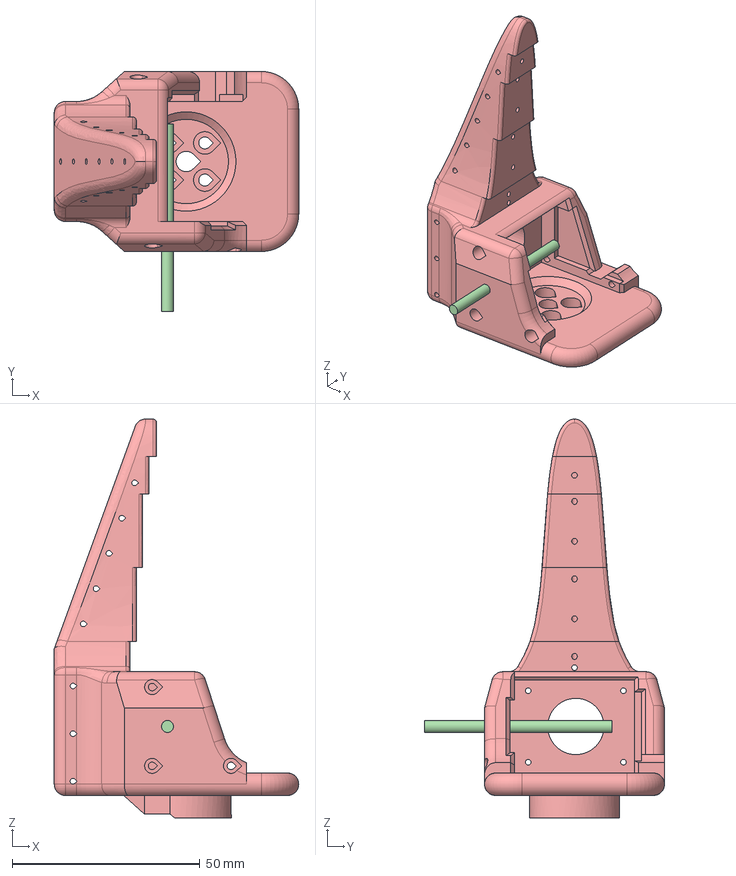
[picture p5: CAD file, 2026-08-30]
cad/accessories/so100_gripper_cam_mount_insert.FCStd
65.2 x 64.0 x 106.4 mm
Upstream SO-100 Wrist Roll
M3 camera-mount clearance
M3 hex-nut pocket
Camera-mount cut tools
SO-100 wrist roll with camera-mount clearance

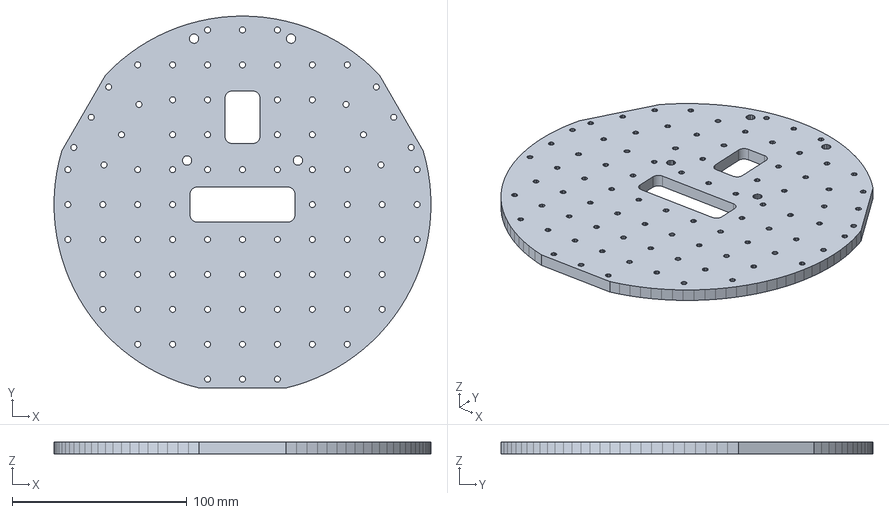
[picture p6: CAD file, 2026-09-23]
cad/parts/base_plate_upper.FCStd
215.9 x 212.9 x 7.00 mm

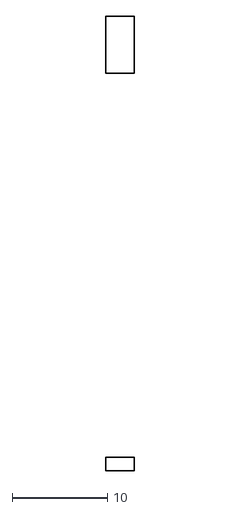
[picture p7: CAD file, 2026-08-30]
cad/reverse_engineered/dynamixel/contours/dynamixel_drive_motor_mount/119.dxf
3.00 x 47.6

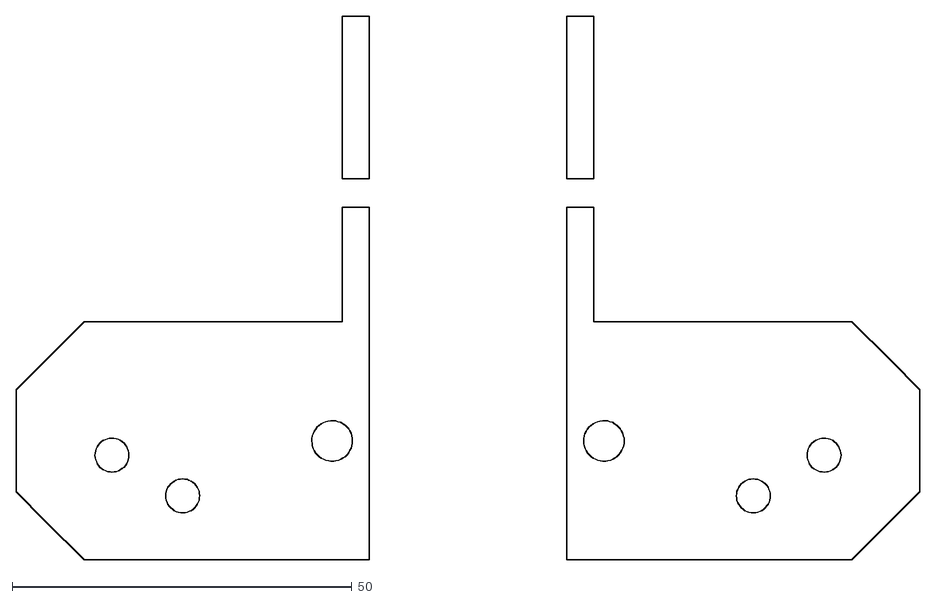
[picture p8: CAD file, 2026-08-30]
cad/reverse_engineered/dynamixel/contours/dynamixel_modified_base_arm/7.dxf
133.0 x 80.0

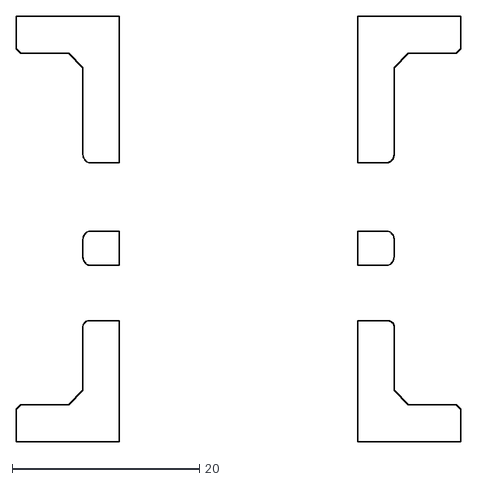
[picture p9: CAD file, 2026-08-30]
cad/reverse_engineered/standard/drive_motor_mount_v2_slices_02/128.dxf
47.5 x 45.5

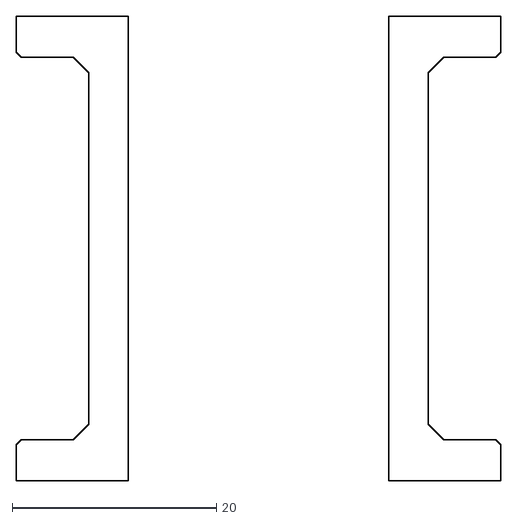
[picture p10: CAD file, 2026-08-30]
cad/reverse_engineered/standard/drive_motor_mount_v2_slices_05/13.dxf
47.5 x 45.5

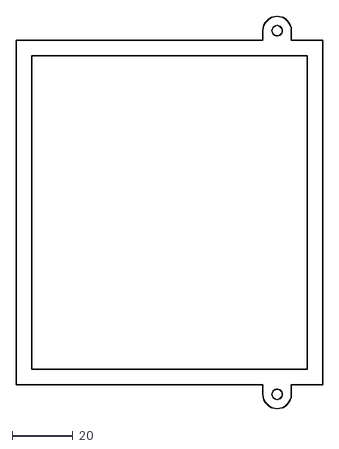
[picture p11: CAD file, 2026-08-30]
cad/reverse_engineered/standard/jetson_holder_component_0_slices_05/7.dxf
101.0 x 129.4

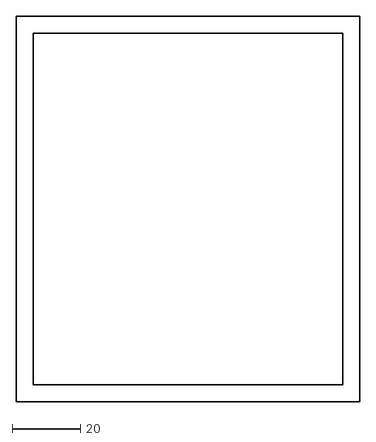
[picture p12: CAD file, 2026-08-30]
cad/reverse_engineered/standard/jetson_holder_component_7_slices_05/3.dxf
101.0 x 113.5

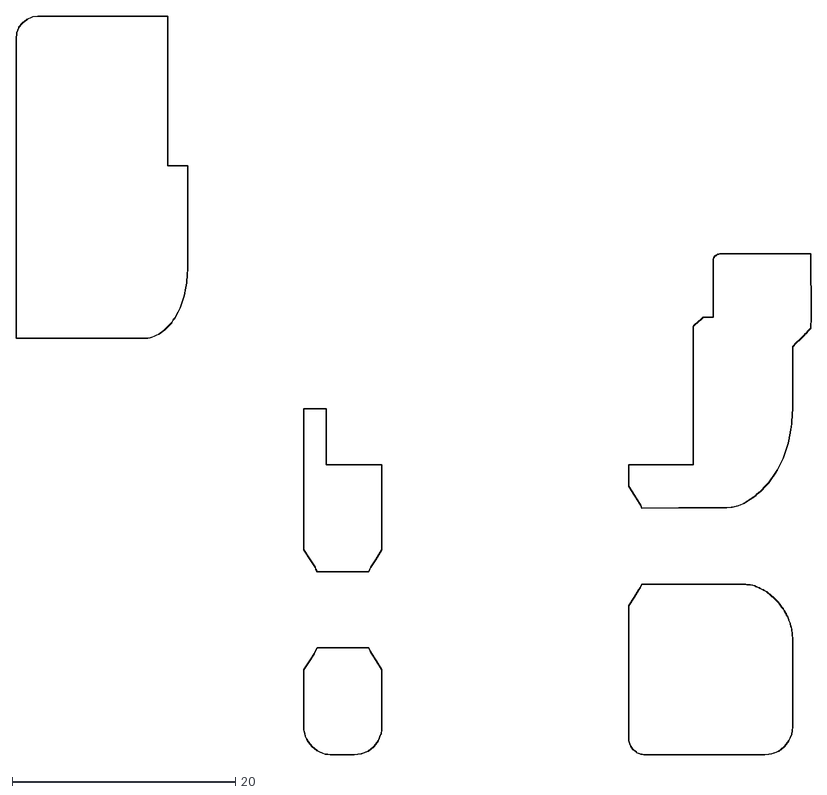
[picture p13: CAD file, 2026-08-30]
cad/reverse_engineered/standard/modified_base_arm_x_slices_023/265.dxf
71.3 x 66.2

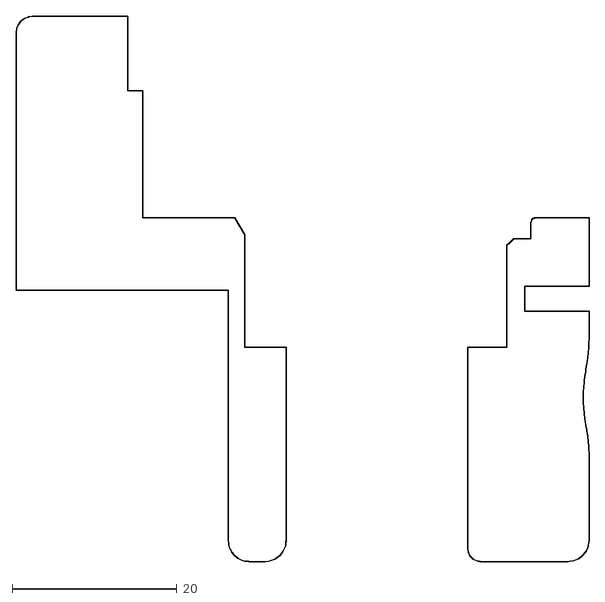
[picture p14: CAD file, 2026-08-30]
cad/reverse_engineered/standard/modified_base_arm_x_tip_9_2.dxf
69.6 x 66.2

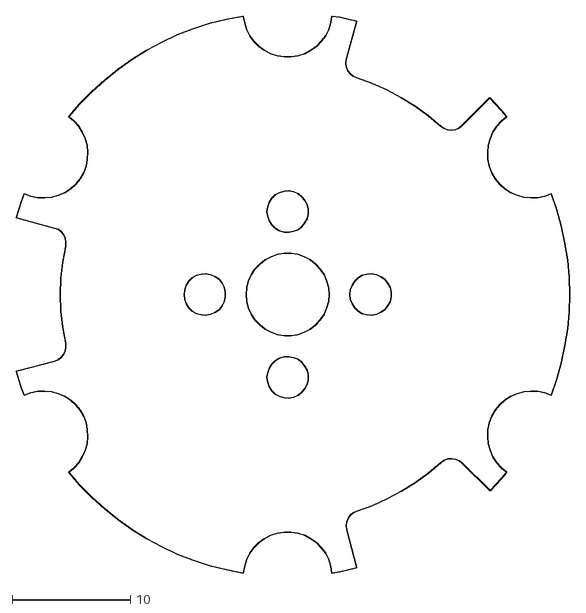
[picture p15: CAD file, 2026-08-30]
cad/reverse_engineered/standard/servo_wheel_hub_slices_025/4.dxf
46.7 x 47.0

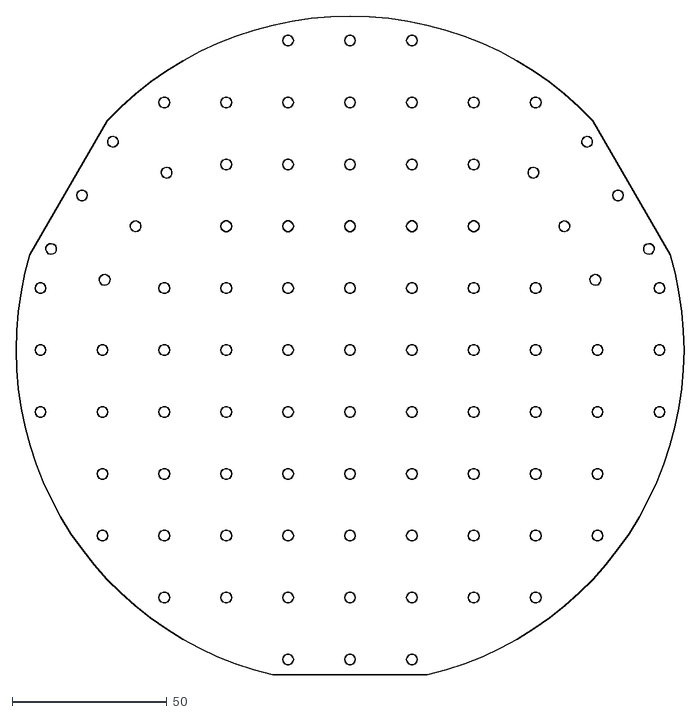
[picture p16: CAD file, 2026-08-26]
laser-cut/generated/base_plate_lower.dxf
215.9 x 212.9

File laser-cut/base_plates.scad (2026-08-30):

// Editable laser profiles of the base plates used by the validated assembly.
// Select one plate, then export as DXF with OpenSCAD.
plate = "lower"; // [lower,upper]

import(plate == "lower"
    ? "generated/base_plate_lower.dxf"
    : "generated/base_plate_upper.dxf");

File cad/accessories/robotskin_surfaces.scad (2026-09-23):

// Measured LeKiwi overlays. Regenerate layout with build_robotskin_surfaces.sh.
include <../upstream/RobotSkin/scad/lib/robotskin.scad>
include <../generated/robotskin/layout.scad>

surface = "top"; // top, floor, ceiling; all exports lie flat with ports facing up.
$fn = 32;
assert(surface == "top" || surface == "floor" || surface == "ceiling");
layout = layouts[surface == "top" ? 0 : surface == "floor" ? 1 : 2];

module overlay() {
  difference() {
    linear_extrude(RM_PLATE_T)
      difference() {
        offset(delta=-0.5) polygon(layout[0]);
        for (cut=layout[1]) polygon(cut);
        for (post=layout[2]) translate([post[0],post[1]]) circle(r=post[2]);
      }
    for (p=layout[3]) translate([p[0],p[1],0]) {
      translate([0,0,RM_PLATE_T]) mirror([0,0,1]) port_cut();
      // Same central M3 passage as RobotSkin's existing through_plate().
      plate_all_through_cuts(1,1);
    }
  }
}

// Flip Y in the print frame, so turning the ceiling over restores chassis XY.
if (surface == "ceiling") mirror([0,1,0]) overlay();
else overlay();

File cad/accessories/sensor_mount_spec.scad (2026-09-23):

// Generated by scripts/sync_sensor_mount_spec.py; edit sensor_mount_spec.json.
astra_pitch = 8.0;
astra_camera_contact_height = 15.5;
astra_m3_spacing = 44.7213595499958;

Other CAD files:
URDF/meshes/reauthored/rpi5_usb_carrier.stl
URDF/meshes/so101/base_so101_v2.stl
3DPrintMeshes/dynamixel_specific/modified_static_side_with_mount.stl
cad/accessories/webcam_base_mount.FCStd
cad/accessories/astra_pro_compact_mount.scad
3DPrintMeshes/dynamixel_specific/Dynamixel_omni_wheel_mount v2.stl
3DPrintMeshes/dynamixel_specific/dynamixel_kiwi_servo_mount.stl
3DPrintMeshes/dynamixel_specific/follower_base.stl
3DPrintMeshes/dynamixel_specific/lipo_battery_mount.stl
3DPrintMeshes/dynamixel_specific/pi_case_bottom.stl
3DPrintMeshes/dynamixel_specific/webcam_base_mount.stl
URDF/meshes/reauthored/4-Omni-Directional-Wheel_Single_Body-v1-1.stl
URDF/meshes/reauthored/4-Omni-Directional-Wheel_Single_Body-v1-2.stl
URDF/meshes/reauthored/4-Omni-Directional-Wheel_Single_Body-v1.stl
URDF/meshes/reauthored/94868A713_NO-THREADS_Female-Threaded-Hex-Standoff-1.stl
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

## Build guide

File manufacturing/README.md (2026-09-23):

# Manufacturing source index

[`parts.json`](parts.json) is the build record for every print asset under
`3DPrintMeshes/`, the two flat base plates, and the robot's extra LD06 mount.
`stl` is the compiled legacy print; `source` is its editable source record;
`validation`, when present, is the direct comparison evidence.

The states mean:

| State | Meaning |
| --- | --- |
| `open_parametric` | Editable FreeCAD or OpenSCAD model is in this repository. |
| `open_contour_stack` | Editable closed DXF profiles and a short OpenSCAD builder reconstruct the solid. |
| `open_cut_profile` | Editable DXF cut profile and its extrusion source are in this repository. |
| `open_multibody_contour_stack` | As above, with the legacy STL's real separate bodies retained separately. |
| `retained_fusion_history` | Original feature history is retained inside `reference/fusion/LeKiwi.f3z`. |
| `external_fusion_history` | Original Fusion history is available at the linked public share but is not vendored because its licence is unstated. |
| `external_fusion_history_with_patch` | The external Fusion history plus a local editable patch. |
| `open_brep` / `derived_brep` | Editable BREP solid, respectively imported or derived rather than the original timeline. |

`surface_validated` means the source was compared bidirectionally with that
specific legacy STL. `component_surface_validated` is the same check per real
body for the malformed multi-body Jetson STL. `compositional_validated` is the
documented external Fusion static-side patch proof; it is deliberately not
reported as a direct export comparison.

Flat production files are [`../laser-cut/base_plates.scad`](../laser-cut/base_plates.scad),
the generated DXFs, and the 1:1 PDFs. The older base-plate STLs are retained as
legacy prints, not as the cutting source.

[`sourced-parts.json`](sourced-parts.json) records manufacturer part numbers,
selected supplier SKUs, and the configuration membership where the BOM names a concrete purchasable part.
It deliberately does not invent an MPN for generic marketplace cables, tool
kits, fastener assortments, or batteries: their supplier SKU is the controlled
identifier until a build configuration selects an exact item.

Run the check after changing the inventory:

```sh
./scripts/verify_manufacturing.sh
```

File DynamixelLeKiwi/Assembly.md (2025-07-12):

# Assembly
> **Estimated time:** 2 hours

*Exact component placements can be visualized in the [Fusion360 Online CAD](https://a360.co/44YAcMn)*

*We assume you already have a [Koch Arm](https://github.com/jess-moss/koch-v1-1) built WITH the modified base and modified static gripper*
### 1. Assemble Wheel Modules (3 per robot)

1. Attach the drive motor to the motor mount using 4 m2x5 tap screws.

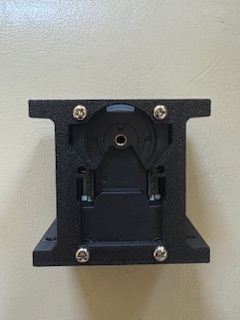
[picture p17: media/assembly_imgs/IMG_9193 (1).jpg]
    

2. Attach the wheel hub to the omniwheel using 2 m4x12 machine screws.

    

3. Attach the wheel hub to the servo horn using 4 m3x16 machine screws.

    

### 2. Bottom Plate Assembly
1. Assemble both plates by attaching the 3D-printed triangular insert to the TB3 plate. Align the outer holes and secure the insert using six M3x8 machine screws and matching nuts (the ones included with the TB3 plates).
    
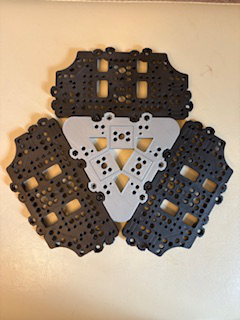
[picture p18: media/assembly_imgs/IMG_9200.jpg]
    

2. Screw each drive motor mount onto the bottom plate using 2 m3x12 machine screws in the front and 2 m2.5x12 machine screws in the back.
   
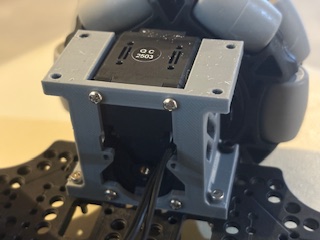
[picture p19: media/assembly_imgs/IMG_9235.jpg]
    

3. Connect the motor wires in series. Insert 2 m3 nuts into the slots on both the battery mount and the base camera mount. Then, attach the battery mount to the bottom plate using two m3x12mm machine screws. Secure the camera mount to the plate using two m3x16mm machine screws.
   
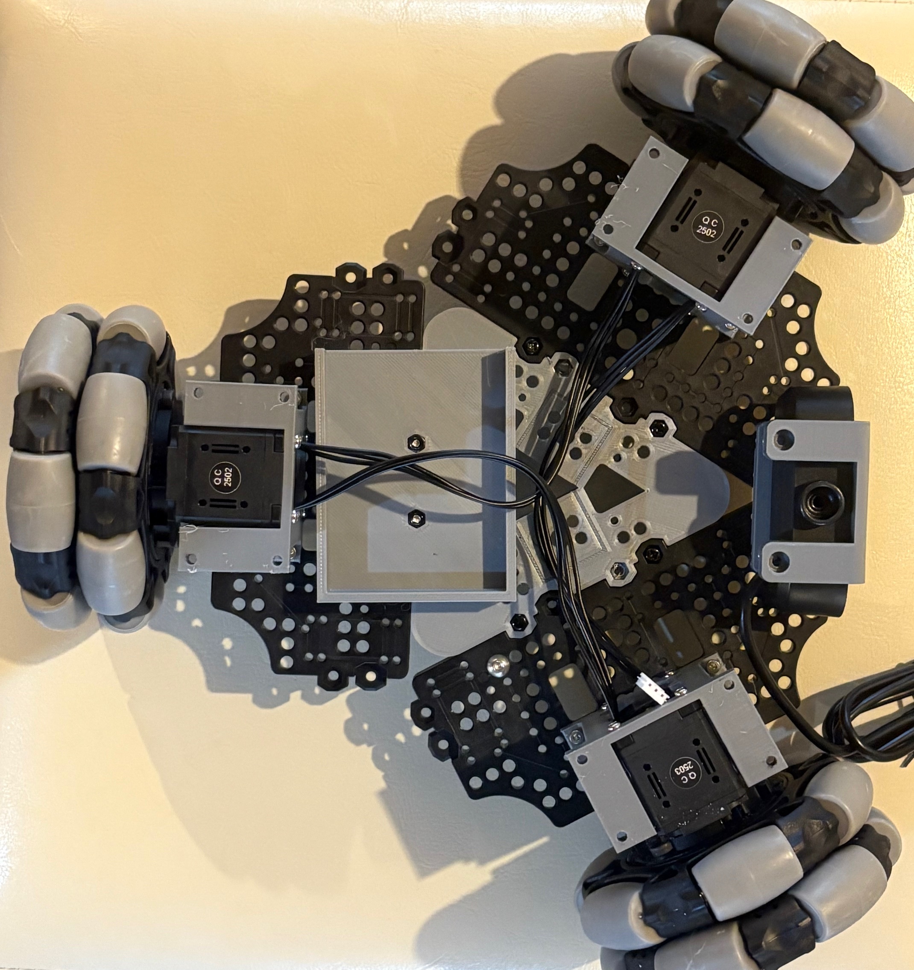
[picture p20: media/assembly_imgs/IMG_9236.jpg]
    

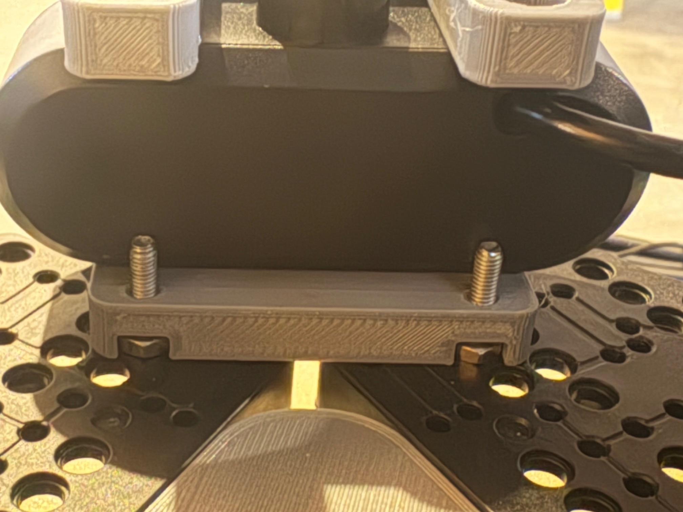
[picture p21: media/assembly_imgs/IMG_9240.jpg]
    

4. Wiring Electronics
   -    Use the wago lever connectors to connect the ground and power battery wire leads to the leads of the 12v->5v converter and the dc barrel plug adapter. 
   

   -    Mount the 12V to 5V converter to the bottom plate using two m4x16mm machine screws and two m4 nuts. Then, connect the unconnected motor wire, the USB cable, and the power wires to the U2D2 power hub board. Attach standoffs to the U2D2 board, and secure it to the base plate using three m3x16mm machine screws.
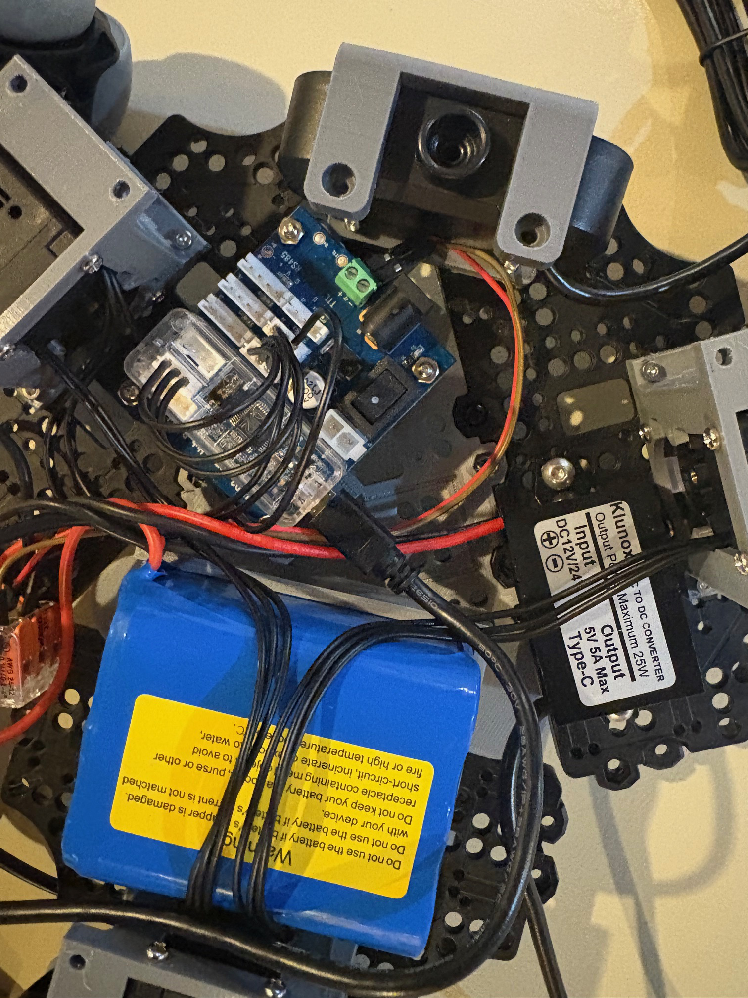
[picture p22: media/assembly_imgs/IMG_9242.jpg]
    

### 3. Top plate Assembly
1. Place the Raspberry Pi 5 into the bottom half of the Pi case and snap on the top cover.

2. If you haven’t already, print the modified Koch arm base and the modified static gripper. Attach the webcam as shown.

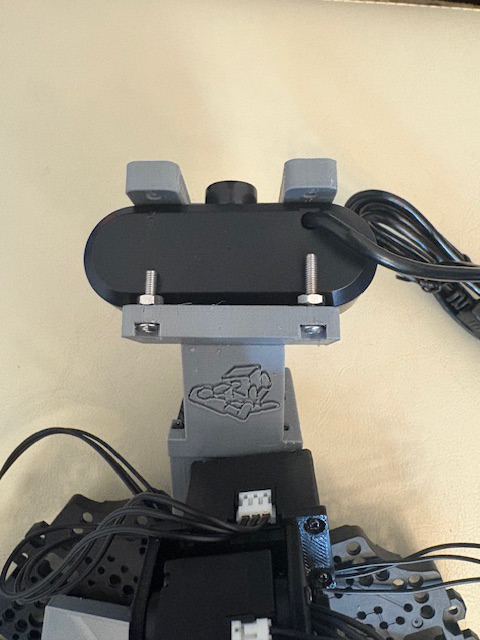
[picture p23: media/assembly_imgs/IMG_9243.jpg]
    
3. Mount the Raspberry Pi to the top plate using two M2x12 machine screws and nuts. Then, secure the Koch arm using four M3x12 machine screws and nuts.

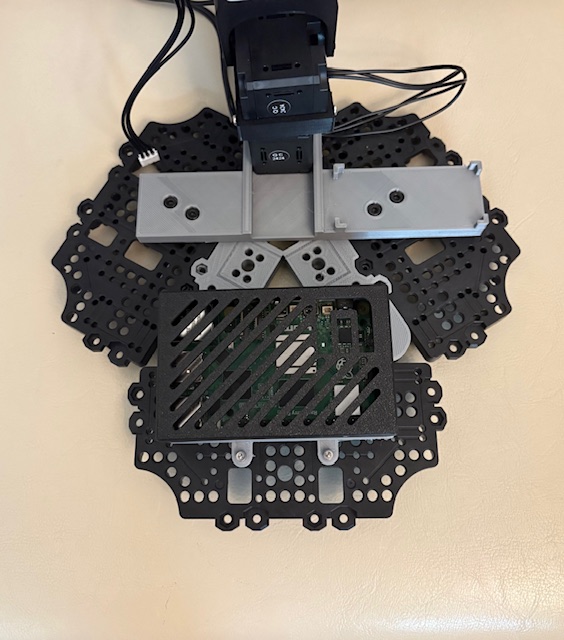
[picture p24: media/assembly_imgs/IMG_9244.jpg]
    

### 4. Final Assembly
1.  Connect the motor wire from the 5V motor to the U2D2 power hub board using jumper cables.  
    -    Route the power and ground wires through the voltage reducer, and then connect them to the appropriate 5V power and GND ports on the power hub board. 
    
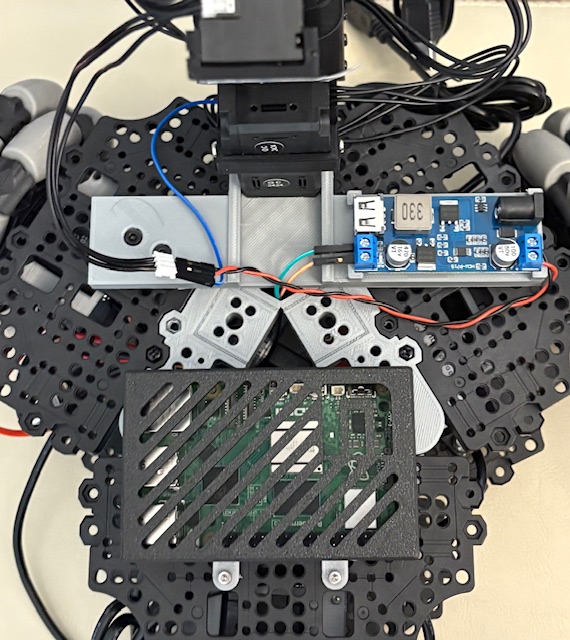
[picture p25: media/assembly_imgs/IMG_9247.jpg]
    
2. Route the data wire (blue wire in picture) directly to the data port on the power hub board. 
    -    Connect the remaining wire from the 12V motor at the base of the arm to the open port on one of the base drive motors.
    
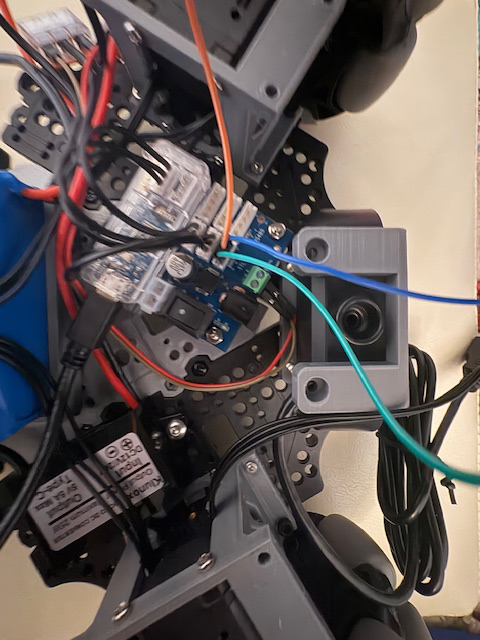
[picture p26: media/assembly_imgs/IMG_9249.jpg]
    

2. Feed the servo controller usb-c to usb-a, 5v usb-c power, and base webcam usb-a wires through the center hole in the top base plate. 

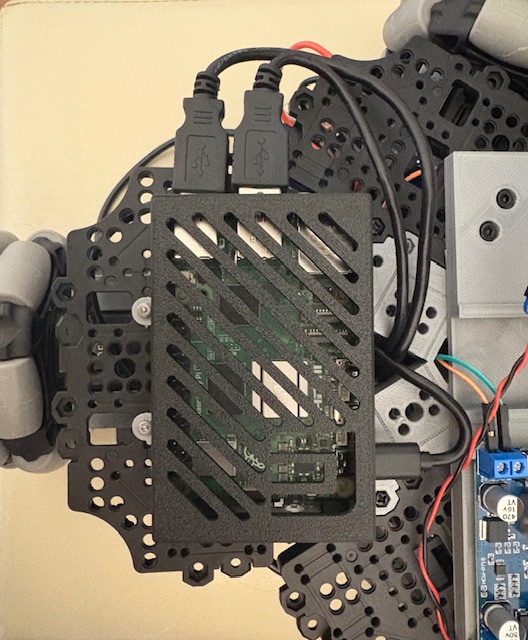
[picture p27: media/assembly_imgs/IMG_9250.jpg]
    

3. Mount the top  plate onto the motor mounts using 6 m3x12 machine screws.

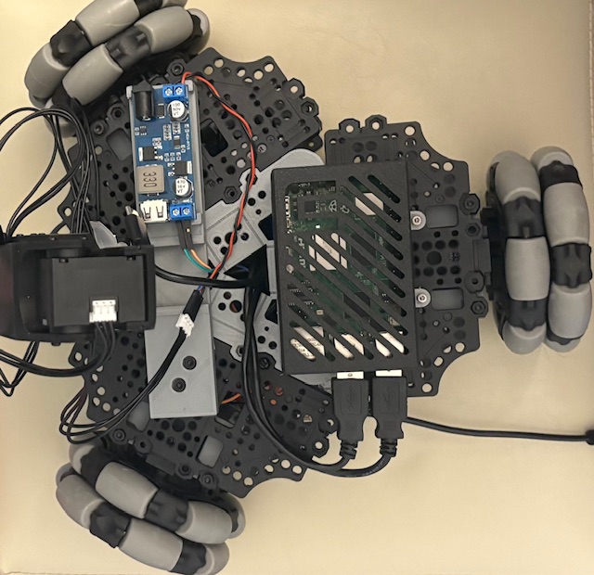
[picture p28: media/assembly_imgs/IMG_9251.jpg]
    

### Plug everything in and its ready!
Power the electronics by plugging in the DC barrel plug adapter to the servo motor controller and the 5v usb-c connector to the raspberry pi 5. The usb cables from the U2D2 power hub board and the cameras can directly be plugged in to the raspberry pi.



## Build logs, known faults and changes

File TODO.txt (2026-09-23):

Open CAD and release work

  - Decide whether the remaining 14 URDF links need native parametric
    FreeCAD models (STEP BREP or canonical-URDF-mesh references instead of
    an editable FreeCAD source). Their exact mapping is in
    cad/reference_mapping.json.

  - Reauthoring the 19 optional/non-URDF print assets with no exact
    editable source is done for 11 of them (see
    cad/reverse_engineered/*/parts.json and
    `3DPrintMeshes/webcam_mount/so100_gripper_cam_mount_insert.FCStd`, an
    exact SO-ARM100 STEP derivative). 8 still have no reauthored source and
    depend on the unavailable Fusion parametric history:
      - 3DPrintMeshes/wrist_camera_mount.stl
      - 3DPrintMeshes/dynamixel_specific/Dynamixel_omni_wheel_mount v2.stl
        and dynamixel_wheel_hub .stl (share the same Fusion component)
      - 3DPrintMeshes/dynamixel_specific/center_triangular_insert.stl
      - 3DPrintMeshes/dynamixel_specific/dynamixel_kiwi_servo_mount.stl
      - 3DPrintMeshes/dynamixel_specific/follower_base.stl
      - 3DPrintMeshes/dynamixel_specific/modified_static_side_with_mount.stl
      - 3DPrintMeshes/dynamixel_specific/pi_case_bottom.stl
      - 3DPrintMeshes/dynamixel_specific/webcam_base_mount.stl

    `drive_motor_mount_v2.stl` and `wrist_camera_mount.stl` are revisions
    distinct from the core URDF models, so each needs its own source;
    `drive_motor_mount_v2.stl` has one, `wrist_camera_mount.stl` does not yet.

  - If native feature histories are required, reauthor the two webcam STEP
    accessories; their current FreeCAD documents are editable BREP imports,
    not reconstructed parametric models.

  - Decide the licensing/provenance treatment for external sources: the
    Raspberry Pi case is CC BY-NC, SO-100/SO-101 remains an external
    Apache-2.0 dependency, and the VEX-derived wheel-hub derivative has no
    verified Apache-compatible exact source.

  - Run a manual FreeCAD GUI edit, relink, export, and Xacro-regeneration
    session to validate the intended human editing flow. The equivalent
    isolated scripted edit flow passed on 2026-08-27; GUI usability remains
    to be confirmed.

  - The three mesh warnings are the canonical omni-wheel meshes, each used by
    one wheel link. They contain non-manifold facets; repairing them removes
    242 of 314244 facets and changes volume, so preserve source fidelity and
    guard the explicit exception with `make verify-mesh-integrity`.

  - Perform physical print, laser-cut, fit, fastener-clearance, strength,
    and full-assembly tests, accounting for material thickness, kerf, printer
    calibration, and print tolerances.

  - Set CAD-derived mass and inertia from chosen material/infill density or
    measured finished-part masses, including hardware.

  - ROS environment validation is partly done: Xacro expansion and
    check_urdf pass under ROS Jazzy. RViz, Gazebo, and MoveIt runtime
    validation after finalizing geometry and mass properties is not done.

Conditional / blocked work

  - Run a denser or full-mesh Hausdorff, clearance, collision, and
    manufacturing-tolerance audit only when a redesign needs a stricter
    threshold than the existing sampled surface check.

  - Original Fusion parametric history is unavailable through an open
    importer. Recreate the omni-wheel and wrist-camera design intent only if
    original sketches/constraints become available or a manual reauthoring
    specification is approved.

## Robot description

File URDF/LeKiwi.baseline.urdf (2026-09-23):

<?xml version='1.0' encoding='utf-8'?>
<robot name="LeKiwi">
    <link name="base_plate_layer1-v5">
        <inertial>
            <origin xyz="-4.730687660675253e-15 -2.7155537377808555e-05 -0.0035000000000000005" rpy="0.0 0.0 0.0" />
            <mass value="1.9468624348344596" />
            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
        </inertial>
        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
    </link>
    <link name="drive_motor_mount-v11-2">
        <inertial>
            <origin xyz="-0.0005387977877578853 0.00013596517365616734 -0.0031122813365712966" rpy="0.0 -0.0 0.0" />
            <mass value="0.047242276734470956" />
            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
        </inertial>
        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
    </link>
    <link name="ST3215_Servo_Motor-v1-2">
        <inertial>
            <origin xyz="0.010251219185305343 -0.016877183343657672 -0.021914257028179583" rpy="0.0 -0.0 0.0" />
            <mass value="0.0658962961901927" />
            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
        </inertial>
        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
    </link>
    <link name="4-Omni-Directional-Wheel_Single_Body-v1-2">
        <inertial>
            <origin xyz="-9.805110055688405e-08 0.015875012090586064 -9.143534264177689e-08" rpy="0.0 -0.0 0.0" />
            <mass value="1.3542854082324305" />
            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
        </inertial>
        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
    </link>
    <link name="omni_wheel_mount-v5-2">
        <inertial>
            <origin xyz="5.9743256737576635e-09 -5.0148034724806225e-09 -0.005522899140934374" rpy="0.0 -0.0 0.0" />
            <mass value="0.1235708646349694" />
            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
        </inertial>
        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
    </link>
    <link name="drive_motor_mount-v11-1">
        <inertial>
            <origin xyz="0.00038715049105024767 -0.0003986280605619008 0.0031122813365712966" rpy="0.0 -0.0 0.0" />
            <mass value="0.047242276734470956" />
            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
        </inertial>
        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
    </link>
    <link name="ST3215_Servo_Motor-v1-1">
        <inertial>
            <origin xyz="0.01025121918530536 0.027816898485662264 -0.00435175717107704" rpy="0.0 -0.0 0.0" />
            <mass value="0.0658962961901927" />
            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
        </inertial>
        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
    </link>
    <link name="omni_wheel_mount-v5-1">
        <inertial>
            <origin xyz="0.004782968825905343 5.966875074037148e-09 0.0027614494161754166" rpy="0.0 -0.0 0.0" />
            <mass value="0.1235708646349694" />
            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
        </inertial>
        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
    </link>
    <link name="4-Omni-Directional-Wheel_Single_Body-v1-1">
        <inertial>
            <origin xyz="0.01374810955311503 -0.007937600014431929 -7.105207897817323e-08" rpy="0.0 -0.0 0.0" />
            <mass value="1.3542854082324305" />
            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
        </inertial>
        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
    </link>
    <link name="drive_motor_mount-v11">
        <inertial>
            <origin xyz="0.00015164729670767764 -0.0005345932342180682 -0.003112281336571299" rpy="0.0 -0.0 0.0" />
            <mass value="0.047242276734470956" />
            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
        </inertial>
        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
    </link>
    <link name="ST3215_Servo_Motor-v1">
        <inertial>
            <origin xyz="0.010251219185305386 -0.010539715142004517 0.02557319387622896" rpy="-6.077163357286271e-64 -0.0 0.0" />
            <mass value="0.0658962961901927" />
            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
        </inertial>
        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
    </link>
    <link name="omni_wheel_mount-v5">
        <inertial>
            <origin xyz="-0.00478297352513172 5.966875045171349e-09 0.002761449724759064" rpy="0.0 -0.0 0.0" />
            <mass value="0.1235708646349694" />
            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
        </inertial>
        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
    </link>
    <link name="4-Omni-Directional-Wheel_Single_Body-v1">
        <inertial>
            <origin xyz="-0.013748211804798878 -0.007937431357202592 -9.805855119449092e-08" rpy="0.0 1.0947644252537633e-47 6.865185903486632e-63" />
            <mass value="1.3542854082324305" />
            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
        </inertial>
        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
    </link>
    <link name="servo_controller_mount-v3">
        <inertial>
            <origin xyz="-2.072913100236695e-30 -3.385736135896877e-14 0.0031621761491414137" rpy="0.0 -0.0 0.0" />
            <mass value="0.12559881449596652" />
            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
        </inertial>
        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
    </link>
    <link name="lipo_battery_mount-v3">
        <inertial>
            <origin xyz="-0.008318729060206734 -4.4408920985006264e-17 -0.0046380028574369405" rpy="0.0 -0.0 0.0" />
            <mass value="0.2984320446179905" />
            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
        </inertial>
        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
    </link>
    <link name="Battery---Battery-5.2-Ah-DC5521-Plug-v2">
        <inertial>
            <origin xyz="-7.797576827959673e-05 -8.300646300726023e-05 0.020000000000000004" rpy="0.0 -0.0 0.0" />
            <mass value="1.2215469988184764" />
            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
        </inertial>
        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
    </link>
    <link name="94868A713_NO-THREADS_Female-Threaded-Hex-Standoff">
        <inertial>
            <origin xyz="2.1864399078485972e-14 1.2010287410706806e-09 -0.02499999330297986" rpy="0.0 -0.0 0.0" />
            <mass value="0.006150070863406618" />
            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
        </inertial>
        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
    </link>
    <link name="base_plate_layer2-v3">
        <inertial>
            <origin xyz="1.4406667835883843e-14 -0.000737848116891558 0.0034999999999999966" rpy="0.0 -0.0 0.0" />
            <mass value="1.9153836917607525" />
            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
        </inertial>
        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
    </link>
    <link name="Bottom-V2-v3">
        <inertial>
            <origin xyz="0.021623799145011228 0.034248555702746215 0.002860022373659428" rpy="0.0 -0.0 0.0" />
            <mass value="0.14588862570926195" />
            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
        </inertial>
        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
    </link>
    <link name="Top-V2-v2">
        <inertial>
            <origin xyz="0.00394392416615524 -0.00045096335632409 0.021552698750372336" rpy="0.0 -0.0 0.0" />
            <mass value="0.1256590419653392" />
            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
        </inertial>
        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
    </link>
    <link name="Camera-Mount-v8">
        <inertial>
            <origin xyz="-0.019889007343132665 0.003162253231103023 0.020248493842242046" rpy="0.0 -0.0 0.0" />
            <mass value="0.09265469509875414" />
            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
        </inertial>
        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
    </link>
    <link name="Camera-Model-v3">
        <inertial>
            <origin xyz="-0.01552129548236823 0.006733132771749837 -0.011599583774026805" rpy="0.0 2.7755575615628914e-17 0.0" />
            <mass value="0.039920058315088616" />
            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
        </inertial>
        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
    </link>
    <link name="94868A713_NO-THREADS_Female-Threaded-Hex-Standoff-1">
        <inertial>
            <origin xyz="2.1866952693017084e-14 1.201028743125221e-09 -0.02499999330297986" rpy="0.0 -0.0 0.0" />
            <mass value="0.006150070863406618" />
            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
        </inertial>
        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
    </link>
    <link name="94868A713_NO-THREADS_Female-Threaded-Hex-Standoff-2">
        <inertial>
            <origin xyz="2.1866952693017084e-14 1.201028743125221e-09 -0.02481596290467566" rpy="0.0 -0.0 0.0" />
            <mass value="0.006150070863406618" />
            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
        </inertial>
        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
    </link>
    <link name="94868A713_NO-THREADS_Female-Threaded-Hex-Standoff-3">
        <inertial>
            <origin xyz="-3.784219515523546e-10 -7.23282504999645e-10 -0.024999993302979855" rpy="0.0 -0.0 0.0" />
            <mass value="0.006150070863406618" />
            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
        </inertial>
        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
    </link>
    <link name="94868A713_NO-THREADS_Female-Threaded-Hex-Standoff-4">
        <inertial>
            <origin xyz="3.784657565120142e-10 3.1253399868091947e-09 -0.02499999330297986" rpy="0.0 -0.0 0.0" />
            <mass value="0.006150070863406618" />
            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
        </inertial>
        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
    </link>
    <link name="94868A713_NO-THREADS_Female-Threaded-Hex-Standoff-5">
        <inertial>
            <origin xyz="2.1862511800918584e-14 1.2010287342434368e-09 -0.02499999330297986" rpy="0.0 -0.0 0.0" />
            <mass value="0.006150070863406618" />
            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
        </inertial>
        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
    </link>
    <joint name="base_plate_layer1-v5_baseplate2bottom_mount" type="fixed">
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

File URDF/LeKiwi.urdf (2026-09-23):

<?xml version="1.0" ?>
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
<robot name="LeKiwi">
  <link name="base_plate_layer1-v5">
    <inertial>
      <origin rpy="0.0 0.0 0.0" xyz="-4.730687660675253e-15 -2.7155537377808555e-05 -0.0035000000000000005"/>
      <mass value="1.9468624348344596"/>
      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
    </inertial>
    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
  </link>
  <link name="drive_motor_mount-v11-2">
    <inertial>
      <origin rpy="0.0 -0.0 0.0" xyz="-0.0005387977877578853 0.00013596517365616734 -0.0031122813365712966"/>
      <mass value="0.047242276734470956"/>
      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
    </inertial>
    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
  </link>
  <link name="ST3215_Servo_Motor-v1-2">
    <inertial>
      <origin rpy="0.0 -0.0 0.0" xyz="0.010251219185305343 -0.016877183343657672 -0.021914257028179583"/>
      <mass value="0.0658962961901927"/>
      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
    </inertial>
    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
  </link>
  <link name="4-Omni-Directional-Wheel_Single_Body-v1-2">
    <inertial>
      <origin rpy="0.0 -0.0 0.0" xyz="-9.805110055688405e-08 0.015875012090586064 -9.143534264177689e-08"/>
      <mass value="1.3542854082324305"/>
      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
    </inertial>
    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
  </link>
  <link name="omni_wheel_mount-v5-2">
    <inertial>
      <origin rpy="0.0 -0.0 0.0" xyz="5.9743256737576635e-09 -5.0148034724806225e-09 -0.005522899140934374"/>
      <mass value="0.1235708646349694"/>
      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
    </inertial>
    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
  </link>
  <link name="drive_motor_mount-v11-1">
    <inertial>
      <origin rpy="0.0 -0.0 0.0" xyz="0.00038715049105024767 -0.0003986280605619008 0.0031122813365712966"/>
      <mass value="0.047242276734470956"/>
      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
    </inertial>
    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
  </link>
  <link name="ST3215_Servo_Motor-v1-1">
    <inertial>
      <origin rpy="0.0 -0.0 0.0" xyz="0.01025121918530536 0.027816898485662264 -0.00435175717107704"/>
      <mass value="0.0658962961901927"/>
      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
    </inertial>
    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
  </link>
  <link name="omni_wheel_mount-v5-1">
    <inertial>
      <origin rpy="0.0 -0.0 0.0" xyz="0.004782968825905343 5.966875074037148e-09 0.0027614494161754166"/>
      <mass value="0.1235708646349694"/>
      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
    </inertial>
    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
  </link>
  <link name="4-Omni-Directional-Wheel_Single_Body-v1-1">
    <inertial>
      <origin rpy="0.0 -0.0 0.0" xyz="0.01374810955311503 -0.007937600014431929 -7.105207897817323e-08"/>
      <mass value="1.3542854082324305"/>
      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
    </inertial>
    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
  </link>
  <link name="drive_motor_mount-v11">
    <inertial>
      <origin rpy="0.0 -0.0 0.0" xyz="0.00015164729670767764 -0.0005345932342180682 -0.003112281336571299"/>
      <mass value="0.047242276734470956"/>
      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
    </inertial>
    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
  </link>
  <link name="ST3215_Servo_Motor-v1">
    <inertial>
      <origin rpy="-6.077163357286271e-64 -0.0 0.0" xyz="0.010251219185305386 -0.010539715142004517 0.02557319387622896"/>
      <mass value="0.0658962961901927"/>
      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
    </inertial>
    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
  </link>
  <link name="omni_wheel_mount-v5">
    <inertial>
      <origin rpy="0.0 -0.0 0.0" xyz="-0.00478297352513172 5.966875045171349e-09 0.002761449724759064"/>
      <mass value="0.1235708646349694"/>
      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
    </inertial>
    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
  </link>
  <link name="4-Omni-Directional-Wheel_Single_Body-v1">
    <inertial>
      <origin rpy="0.0 1.0947644252537633e-47 6.865185903486632e-63" xyz="-0.013748211804798878 -0.007937431357202592 -9.805855119449092e-08"/>
      <mass value="1.3542854082324305"/>
      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
    </inertial>
    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
  </link>
  <link name="servo_controller_mount-v3">
    <inertial>
      <origin rpy="0.0 -0.0 0.0" xyz="-2.072913100236695e-30 -3.385736135896877e-14 0.0031621761491414137"/>
      <mass value="0.12559881449596652"/>
      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
    </inertial>
    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
  </link>
  <link name="lipo_battery_mount-v3">
    <inertial>
      <origin rpy="0.0 -0.0 0.0" xyz="-0.008318729060206734 -4.4408920985006264e-17 -0.0046380028574369405"/>
      <mass value="0.2984320446179905"/>
      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
    </inertial>
    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
  </link>
  <link name="Battery---Battery-5.2-Ah-DC5521-Plug-v2">
    <inertial>
      <origin rpy="0.0 -0.0 0.0" xyz="-7.797576827959673e-05 -8.300646300726023e-05 0.020000000000000004"/>
      <mass value="1.2215469988184764"/>
      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
    </inertial>
    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

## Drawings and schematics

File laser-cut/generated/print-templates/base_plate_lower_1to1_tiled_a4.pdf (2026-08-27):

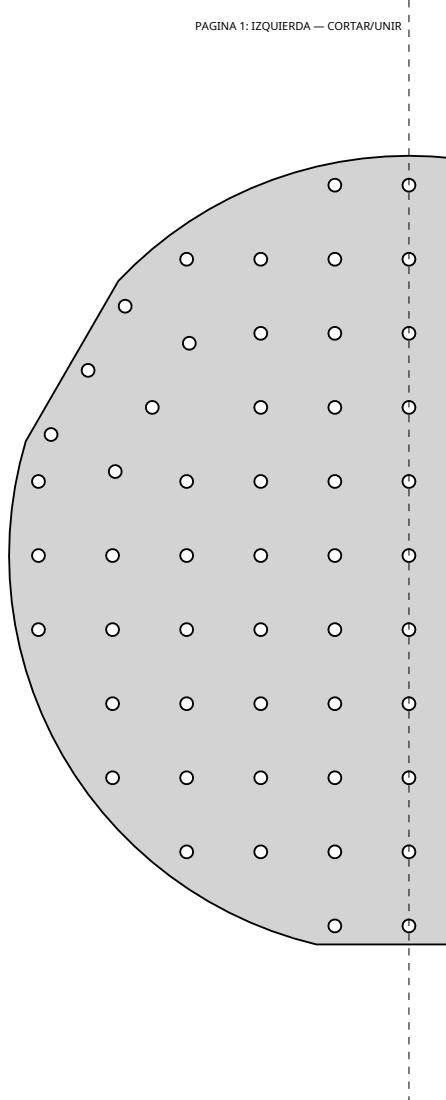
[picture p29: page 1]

PAGINA 1: IZQUIERDA — CORTAR/UNIR

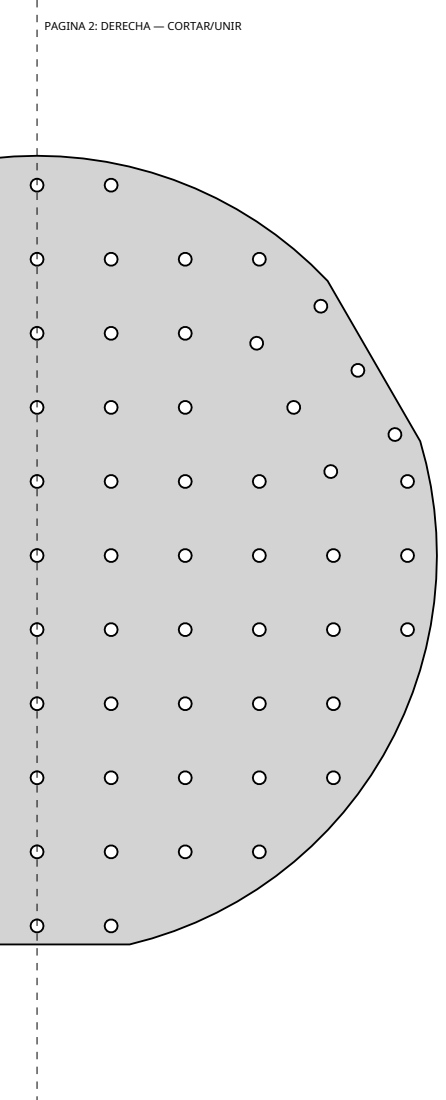
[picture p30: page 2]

PAGINA 2: DERECHA — CORTAR/UNIR

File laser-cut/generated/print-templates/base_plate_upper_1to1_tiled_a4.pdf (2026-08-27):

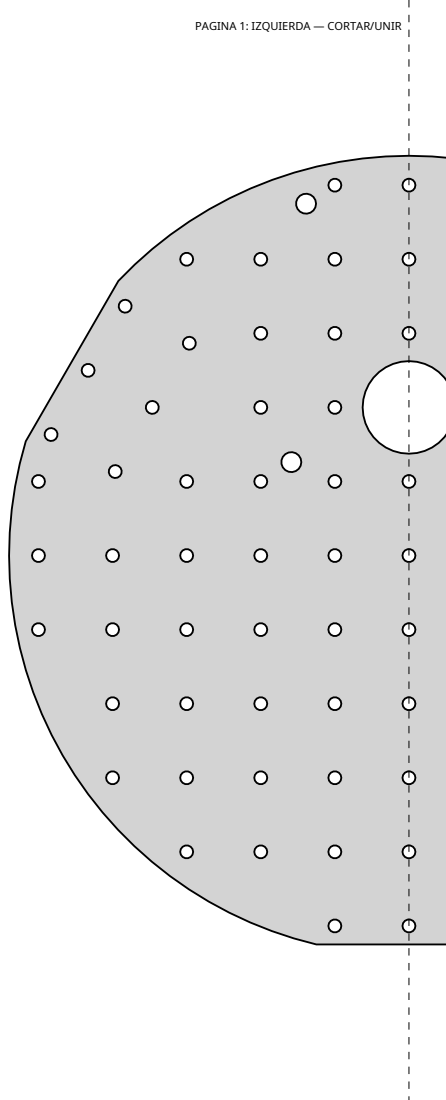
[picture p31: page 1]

PAGINA 1: IZQUIERDA — CORTAR/UNIR

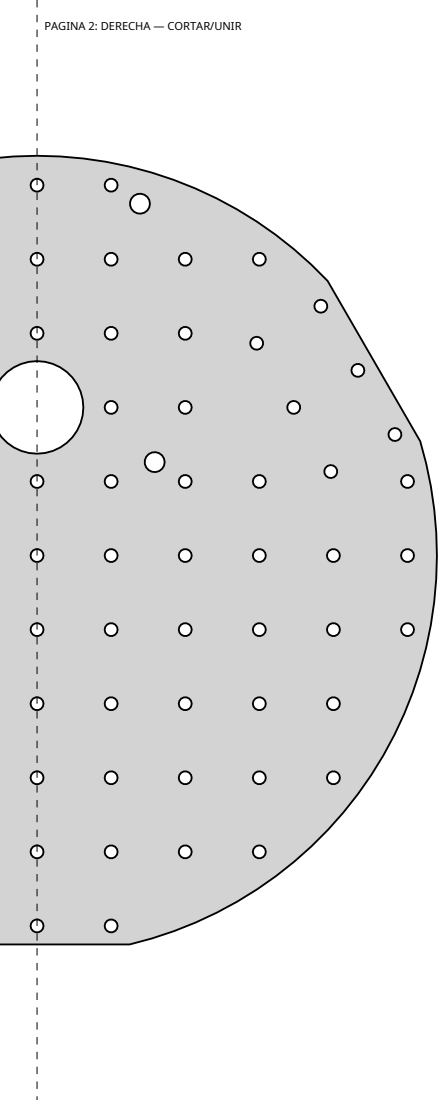
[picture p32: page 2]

PAGINA 2: DERECHA — CORTAR/UNIR

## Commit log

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2025-07-11 added meshes and updated 3DPrinting.md
    [Dynamixel_omni_wheel_mount v2.stl, center_triangular_insert.stl, dynamixel_kiwi_servo_mount.stl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]
2026-08-26 Add laser-cut base plate profiles
    [base_plate_lower.dxf, base_plate_upper.dxf, base_plates.scad]
2026-08-26 Add FreeCAD assembly and Xacro baseline
    [LeKiwi.urdf.xacro]
2026-08-26 Add deterministic FreeCAD robot export
    [LeKiwi.urdf.xacro]
2026-08-26 Add editable FreeCAD base plate sources
    [base_plate_lower.FCStd, base_plate_lower.dxf, base_plate_upper.FCStd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]
2026-08-26 Link editable base plates to robot export
    [LeKiwi.urdf.xacro, base_plate_layer1-v5.stl, base_plate_layer2-v3.stl]
2026-08-26 Complete FreeCAD link migration
    [4-Omni-Directional-Wheel_Single_Body-v1-1.stl, 4-Omni-Directional-Wheel_Single_Body-v1-2.stl, 4-Omni-Directional-Wheel_Single_Body-v1.stl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]
2026-08-26 Reauthor native LeKiwi printed parts
    [Camera-Mount-v8.stl, ST3215_Servo_Motor-v1-1.stl, Wrist-Camera-Mount-v11.stl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]
2026-08-26 Add published accessory CAD sources and fidelity audit
    [webcam_base_mount.FCStd, webcam_wrist_mount.FCStd]
2026-08-26 Rebuild servo controller mount features
    [servo_controller_mount-v3.stl, servo_controller_mount.FCStd]
2026-08-26 Rebuild LiPo mount clearances
    [lipo_battery_mount-v3.stl, lipo_battery_mount.FCStd]
2026-08-26 Rebuild drive mount tray features
    [drive_motor_mount-v11-1.stl, drive_motor_mount-v11-2.stl, drive_motor_mount-v11.stl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]
2026-08-26 Rebuild base camera mount features
    [Camera-Mount-v8.stl, base_camera_mount.FCStd]
2026-08-26 Rebuild wrist camera mount features
    [Wrist-Camera-Mount-v11.stl, wrist_camera_mount.FCStd]
2026-08-26 Rebuild omni wheel mount from sectional profiles
    [omni_wheel_mount-v5-1.stl, omni_wheel_mount-v5-2.stl, omni_wheel_mount-v5.stl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]
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2026-08-30 feat(cad): add RobotSkin LD06 mount
    [LeKiwi.urdf.xacro, ld06_body.stl, robotskin-lidar-mount.stl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]
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2026-08-30 cad: add editable SO-100 webcam gripper source
    [so100_gripper_cam_mount_insert.FCStd]
2026-08-30 cad: build RobotSkin lidar mount from scad source
    [robotskin-lidar-mount.stl, robotskin_lidar_mount.stl]
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2026-08-30 cad: add parametric legacy holder sources
    [holders.scad]
2026-08-30 cad: validate corrected gripper insert source
    [so100_gripper_cam_mount_insert.FCStd]
2026-08-30 cad: recover Dynamixel print sources
    [0.dxf, 1.dxf, 10.dxf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]
2026-08-30 cad: recover standard print sources
    [0.dxf, 1.dxf, 10.dxf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]
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2026-08-30 cad: tighten drive mount source validation
    [0.dxf, 1.dxf, 10.dxf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]
2026-08-30 cad: index validated legacy print sources
    [base_plates.scad, dynamixel.scad, holders.scad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]
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2026-08-31 cad: add Astra Pro grid mount plate
    [astra_pro_mount_plate.scad, astra_pro_mount_plate.stl]
2026-08-31 cad: store Astra mount as binary STL
    [astra_pro_mount_plate.stl]
2026-08-31 revert: remove incorrect Astra foot adapter
    [astra_pro_mount_plate.scad, astra_pro_mount_plate.stl]
2026-08-31 cad: add base-removed Astra Pro mount
    [astra_pro_base_camera_mount.scad, astra_pro_base_camera_mount.stl]
2026-08-31 feat: replace LeKiwi arm model with SO-101
    [LeKiwi.urdf, LeKiwi.urdf.xacro, base_motor_holder_so101_v1.stl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]
2026-08-31 revert: remove misoriented Astra mount
    [astra_pro_base_camera_mount.scad, astra_pro_base_camera_mount.stl]
2026-08-31 fix: keep SO-101 tool frame massless
    [LeKiwi.urdf, LeKiwi.urdf.xacro]
2026-08-31 fix: omit massless accessory inertials
    [LeKiwi.urdf.xacro]
2026-08-31 fix: give lidar joints unique frame names
    [LeKiwi.urdf.xacro]
2026-08-31 cad: add upright Astra between-wheel mount
    [astra_pro_between_wheels_mount.scad, astra_pro_between_wheels_mount.stl]
2026-08-31 cad: prototype cylindrical SO-101 arm
    [design.scad, kinematics.scad]
2026-08-31 revert: remove oversized Astra mast
    [astra_pro_between_wheels_mount.scad, astra_pro_between_wheels_mount.stl]
2026-08-31 cad: add compact Astra Pro mount
    [astra_pro_compact_mount.scad, astra_pro_compact_mount.stl]
2026-08-31 cad: rebuild cylindrical SO101 from common geometry
    [design.scad, kinematics.scad]
2026-08-31 cad: add verified cylindrical arm base mounts
    [design.scad, kinematics.scad]
2026-09-01 cad: smooth Astra mount wedge
    [astra_pro_compact_mount.scad, astra_pro_compact_mount.stl]
2026-09-01 fix: seat Astra camera against mount
    [astra_pro_compact_mount.scad, astra_pro_compact_mount.stl]
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2026-09-01 cad: reauthor SO-101 wrist flex in CadQuery
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2026-09-01 Revert "cad: preserve wrist motor envelope and volume"
    This reverts commit 53730d8ea02ee933a2ec3e42894f5f9907ce9b26.
2026-09-01 Revert "cad: reauthor SO-101 wrist flex in CadQuery"
    This reverts commit a829c94465d6543b6a9d6eb6abe1c7687c3bda94.
2026-09-01 cad: tighten Astra fit and add M3 inserts
    [astra_pro_compact_mount.scad, astra_pro_compact_mount.stl]
2026-09-01 fix: fit Astra pocket and bottom-load inserts
    [astra_pro_compact_mount.scad, astra_pro_compact_mount.stl]
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2026-09-05 fix: align sensor and arm mounts
    [LeKiwi.urdf.xacro, Rotation_Pitch_08i-v1.stl, ST3215_Servo_Motor-v1-2.stl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]
2026-09-05 fix: preserve SO-101 assembly datum and regenerate sensor and wrist assets
    [LeKiwi.urdf.xacro, ST3215_Servo_Motor-v1-1.stl, ST3215_Servo_Motor-v1.stl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]
2026-09-05 fix: align SO-101 shoulder axes across source frame conventions
    [LeKiwi.urdf.xacro]
2026-09-05 build: reject stale CAD sources before vendoring robot models
    [ST3215_Servo_Motor-v1-1.stl, astra_pro_compact_mount.stl, robotskin_lidar_mount.stl]
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2026-09-05 fix: face SO-101 outward and mount lidar on former Pi holes
    [LeKiwi.urdf.xacro, ST3215_Servo_Motor-v1-2.stl, robotskin_lidar_mount.stl]
2026-09-05 fix: place Astra on existing left-edge mounting holes
    [LeKiwi.urdf.xacro, ST3215_Servo_Motor-v1-1.stl, astra_pro_compact_mount.scad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]
2026-09-05 fix: anchor Astra to the diagonal holes indicated in photo
    [LeKiwi.urdf.xacro, ST3215_Servo_Motor-v1-1.stl, astra_pro_compact_mount.scad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]
2026-09-05 fix: render the complete SO-101 arm yellow
    [LeKiwi.urdf.xacro, ST3215_Servo_Motor-v1-1.stl, ST3215_Servo_Motor-v1-2.stl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]
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2026-09-06 fix: emit a valid canonical xacro
    [LeKiwi.urdf.xacro]
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2026-09-06 fix: hide link-local CAD export sources
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2026-09-06 cad: replace vented part 8 covers with round housing
2026-09-07 cad: add RobotSkin overlays for the LeKiwi chassis
    [robotskin_surfaces.scad]
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2026-09-07 cad: align RobotSkin skins with physical wheel assemblies
    [robotskin_surfaces.scad]
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2026-09-08 cad: align six chassis rods with measured mounting holes
    [LeKiwi.urdf.xacro]
2026-09-08 cad: install v2 wheel cages and reserve 4 mm RobotSkin clearance
    [LeKiwi.urdf.xacro, ST3215_Servo_Motor-v1-1.stl, ST3215_Servo_Motor-v1-2.stl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]
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2026-09-08 cad: add matching rounded cable windows to upper plate and skins
    [ST3215_Servo_Motor-v1-2.stl, astra_pro_compact_mount.stl, base_plate_layer2-v3.stl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]
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2026-09-09 cad: record verified arm screw access clearances
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2026-09-23 feat(cad): mount the RobotSkin RPi 5 stack on the upper plate
    A 12x10 through plate bolts to real upper-plate holes at the rear right
    (pose in sensor_mount_spec.json); the USB carrier and protection table lock
    into its ports. The FreeCAD assembly, reauthored meshes and Xacro are
    regenerated and the mount checks verify the hole alignment.
    [LeKiwi.urdf.xacro, rpi5_table.stl, rpi5_table_installed.scad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]
2026-09-23 fix(urdf): generate LeKiwi.urdf and fail on a stale committed model
    URDF/LeKiwi.urdf was the untouched upstream model (old Pi case, no sensors,
    old arm pose and masses) while consumers read it as the robot. Keep it as
    URDF/LeKiwi.baseline.urdf for the migration and semantics checks, and have
    export_robot.sh write the plain-URDF expansion of the Xacro instead.
    verify_robot.sh now checks the manifest and compares its rebuild with the
    committed Xacro, URDF and meshes (meshes as canonical triangle sets, since
    exports reorder triangles). That removed three committed meshes no export
    produces: the removed Pi case and the superseded SO-101 wrist.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
    [Bottom-V2-v3.stl, LeKiwi.baseline.urdf, LeKiwi.urdf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]
2026-09-23 fix(ci): pin FreeCAD with flatpak update on older Flatpak
2026-09-23 fix(ci): install networkx for trimesh hole filling
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2026-09-23 fix(cad): validate CAD-derived inertials physically, drop chassis-rod import
    verify_xacro.py exact-matched every link's baseline <inertial> against the
    generated one, so activating UseCadMass via attach_cad_part.py (documented in
    cad/README.md) would always fail verification: the baseline URDF never had
    real CAD-derived mass. export_xacro.py now records which links have
    UseCadMass=True in cad_mass_links.json next to its output; verify_xacro.py
    skips exact-matching those links' <inertial> and instead checks the exported
    mass and inertia tensor physically (positive finite mass, positive-definite
    tensor, principal moments satisfying the rotational triangle inequality).
    Also move the chassis ro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
2026-09-23 fix(cad): skip resaving the assembly when sensor mounts are unchanged
    Every export ran sync_robotskin_lidar.sh -> add_lidar_accessory.py, which
    unconditionally removed and re-added the lidar/LD06/Astra mounts and saved
    cad/assembly/LeKiwi.FCStd, churning the binary even when nothing changed.
    Compare each mount's recorded source (OpenSCAD source hash, not the
    regenerated STL's: OpenSCAD's STL export is not byte-stable across identical
    runs) and joint pose against its current inputs, and skip the rebuild and
    save when they already match and the Pi case is already removed. Verified
    empirically: two consecutive real exports now leave LeKiwi.FCStd's hash
    unchanged.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
2026-09-23 fix(cad): clear stale reauthored meshes before exporting
    export_cad_meshes.py only ever wrote meshes for links currently in
    LeKiwiLinks with CadParts; a link removed or renamed left its old .stl
    behind in URDF/meshes/reauthored/ forever. Clear the directory's existing
    .stl files before the export loop so removed links' meshes actually
    disappear (verified: the removed Pi case's reauthored/Bottom-V2-v3.stl and
    Top-V2-v2.stl are now pruned on export instead of lingering).
2026-09-23 fix(cad): compare wheel-mount link bbox against the link-local shape
    link_bbox_error used the same source_shape/reference expression as
    source_bbox_error (copy-paste), so it never actually measured the exported
    link's own geometry. Compare against links[item["urdf_link"]].CadParts[0].Shape
    instead.
2026-09-23 fix(cad): make compare_reauthored_assets strict by default
    A failed shape-fidelity comparison only failed the run with --strict, so
    verify_robot.sh (which never passed it) could not catch a regression here.
    Make strict the default and add --report-only to keep the old write-only
    behavior explicitly. Also reuse cad_utils.native_part_replacements() instead
    of a third inline copy of the same comprehension.
2026-09-23 refactor(scripts): dedupe Pi-case links and native part replacements
    verify_cad_migration.py had its own copies of the removed-Pi-case link set
    and the native_parts.json reference-mesh comprehension; use cad_utils's
    shared PI_CASE_LINKS and native_part_replacements() instead.
2026-09-23 refactor(scripts): use require() and dedupe pose/link helpers in verify scripts
    verify_sensor_mounts.py and verify_arm_mount.py used bare asserts (silently
    skipped under python -O) and each redefined a shoulder-pose tree walk / the
    Pi-case link set / the so101_yellow RGBA literal. Convert to cad_utils.require(),
    reuse cad_utils.PI_CASE_LINKS and SO101_YELLOW_RGBA, and reuse
    replace_arm_with_so101.joint_pose() for the shoulder pose instead of
    re-implementing the same parent-chain walk.
2026-09-23 refactor(scripts): dedupe object_name(), prune retired STEP_OBJECTS entries
    object_name(link_name) duplicated cad_utils's prefix+sanitize regex; delegate
    to cad_utils.object_name("CadReference_", link_name) instead (aliased on
    import to avoid colliding with the unrelated object_name loop variable used
    while building NATIVE_PARTS).
    Prune the 18 retired SO-100 arm STEP_OBJECTS entries (Base_08q-v1,
    Camera-Model-v3-1, Moving_Jaw_08d-v1, Passive_Horn_01-v1, Rotation_Pitch_08i-v1,
    SO_ARM100_08k_*, STS3215_03a-v1*, WaveShare_Mounting_Plate_01d-v1,
    Wrist-Camera-Mount-v11, Wrist_Roll_08c-v1, Wrist_Roll_Pitch_08i-v1): none of
    those links are in the current baseline URDF (replaced by so101_* links) o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
2026-09-23 build(cad): delete export_xacro.sh, track chassis rod positions in manifest
    export_xacro.sh was a partial copy of export_robot.sh (no mesh export, lidar
    sync, wrist regen, or manifest update) and had drifted out of sync with the
    real pipeline. Delete it and drop it from model_manifest.py's input list;
    nothing else referenced it. Add the new cad/chassis_rod_positions.json to the
    manifest inputs alongside the existing wheel_mount_v2_poses.json, since both
    now feed verify_xacro.py's geometry checks the same way.
2026-09-23 chore(cad): remove meshes unreferenced by the URDF, Xacro, or any script
    12 meshes are the retired SO-100 arm's STEP BREP references
    (SO_ARM100_08k_*, STS3215_03a-v1*, Passive_Horn_01-v1, Rotation_Pitch_08i-v1,
    WaveShare_Mounting_Plate_01d-v1, Wrist-Camera-Mount-v11): absent from
    URDF/LeKiwi.urdf, URDF/LeKiwi.urdf.xacro, and cad/reference_mapping.json's
    "canonical URDF STL mesh reference" set that verify_mesh_integrity.py checks
    unconditionally (the only script found reading that mapping without
    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
    [Passive_Horn_01-v1.stl, Rotation_Pitch_08i-v1.stl, SO_ARM100_08k_116_Square-v1.stl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]
2026-09-23 refactor(scripts): replace trivial FreeCAD-script wrappers with a Makefile
    17 scripts/*.sh files each only forwarded to run_freecad_script.sh (or, for
    the two plain-Python ones, invoked python3 directly) with fixed or
    passed-through arguments. Replace them with named Makefile targets and
    update every doc reference (cad/README.md, cad/accessories/README.md,
    cad/parts/README.md). Kept every wrapper with real logic (export_robot,
    verify_robot, sync_robotskin_lidar, build_robotskin_surfaces,
    verify_arm_sources, migrate_reference_links, run_freecad_script,
    install_freecad).
    Also document the FreeCAD/OpenSCAD/xacro/CadQuery prerequisites and
    requirements.txt in cad/README.md, note that verify_xac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
2026-09-23 build(scripts): strengthen verify_robot.sh, use deleted-wrapper scripts directly
    Add python3 scripts/model_manifest.py --check, python3 -m pytest scripts
    (with the ROS launch_testing plugins disabled, since they otherwise try to
    collect every test_*.py as a ROS launch test when setup.bash is sourced),
    compare_reauthored_assets.py (now strict by default), and a byte-for-byte
    diff of the committed URDF/LeKiwi.urdf.xacro against a fresh build (the
    frozen URDF/LeKiwi.urdf baseline is exempt). Replace the four calls into
    deleted trivial wrapper scripts with direct run_freecad_script.sh
    invocations. verify_manufacturing.sh absorbs the two deleted wrappers'
    former one-line bodies directly.
    Co-Auth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
2026-09-23 fix(scripts): make export_robot.sh's cad/parts symlink idempotent
    ln -s failed if the symlink from a previous --output-root run already
    existed. Use ln -sfn so re-running export_robot.sh against the same
    output-root directory doesn't fail.
2026-09-23 style(scripts): silence ruff E402 for export_so101_wrist's required import order
    The so101_part8 import must follow the sys.path.insert() that makes it
    resolvable; mark it explicitly instead of leaving an unexplained lint error.
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2026-09-23 build: refresh generated robot model
    Regenerated via ./scripts/export_robot.sh after the above script fixes.
    cad/assembly/LeKiwi.FCStd picks up add_lidar_accessory.py's new SourceHash/
    SourceRadiusMm/SourceHeightMm tracking properties (a one-time migration cost;
    verified the following export left the FCStd byte-identical). The three
    reauthored meshes differ only in FreeCAD/OpenSCAD's non-deterministic facet
    order and float formatting, not geometry. URDF/LeKiwi.urdf.xacro is
    unchanged: verified byte-identical to a fresh rebuild.
    [ST3215_Servo_Motor-v1.stl, astra_pro_compact_mount.stl, robotskin_lidar_mount.stl]
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2026-09-23 build: refresh generated robot model after rebasing onto main's RPi5 stack
    Regenerated via ./scripts/export_robot.sh against the fully merged tree (RPi5
    stack, URDF/LeKiwi.baseline.urdf split, and this branch's script fixes).
    cad/assembly/LeKiwi.FCStd's second save reflects add_lidar_accessory.py's new
    SourceHash tracking properties for the RobotSkin lidar/Astra mounts, plus the
    RPi5 mount script's own save; the OpenSCAD-derived meshes (lidar, Astra, and
    the three RPi5 parts) differ only in non-deterministic facet order and float
    formatting, not geometry. Verified URDF/LeKiwi.urdf.xacro, URDF/LeKiwi.urdf,
    and URDF/LeKiwi.baseline.urdf are byte-identical to this rebuild.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
    [astra_pro_compact_mount.stl, robotskin_lidar_mount.stl, rpi5_table.stl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]
